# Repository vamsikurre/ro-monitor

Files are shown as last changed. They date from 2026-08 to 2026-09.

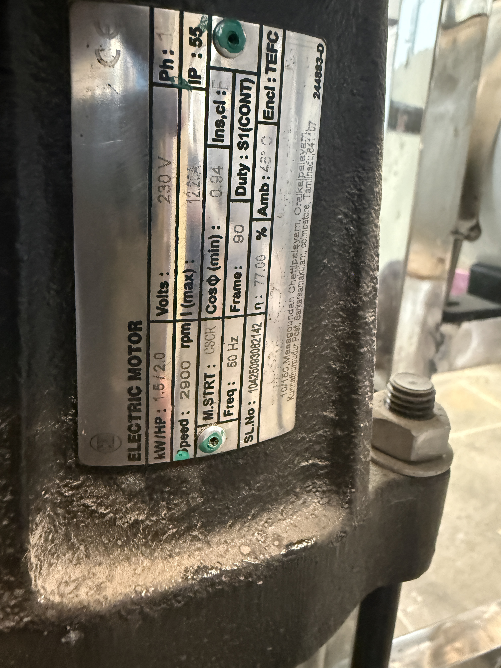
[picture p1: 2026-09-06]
images/hardware/nameplate_hpp_motor_2hp.jpg

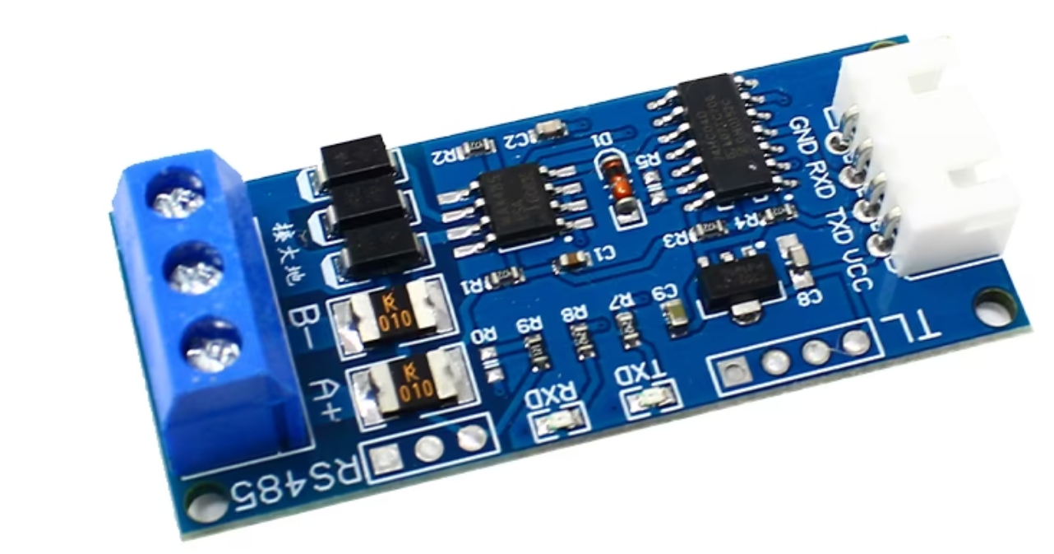
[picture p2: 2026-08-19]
images/hardware/RS485-transcever-board-f.png

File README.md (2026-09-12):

# RO-Monitor: Industrial RO Plant Remote Telemetry & Monitoring System

A non-invasive, galvanically isolated telemetry, environmental, and multi-zone liquid level monitoring system for commercial/industrial Reverse Osmosis (RO) plants.

The system interfaces with an existing **Aster NXT 11** RO controller, distributed rooftop/battery-room storage and environmental nodes using an **ESP32-S Master Hub** over an **RS485 Daisy-Chain Bus**, and connects to **Ground Floor Sump and Motor Starter Nodes** over **Local Wi-Fi (LAN)**. It features a responsive **Local Web Dashboard** and native **ESP RainMaker Cloud** integration for iOS & Android mobile telemetry and push notifications.

---

## 1. System Architecture Overview

```
                                      +------------------------------------------+
                                      |              230V AC Mains               |
                                      +--------------------+---------------------+
                                                           |
                                                           v
                                               +-----------------------+
                                               |  Hi-Link HLK-20M12    |
                                               |  (12V DC / 20W Power) |
                                               +-----------+-----------+
                                                           |
                                                           | 12V DC Distributed Bus
                                                           v
 [NO TERMINATOR - see docs/WIRING.md 12.3]
+----------------------------------------------------------------------------------------------------+
|                                    ESP32-S CENTRAL HUB (RO ROOM)                                   |
|  - Microcontroller: ESP32-S (38-Pin)                                                               |
|  - RS485 Interface: XY-485 Hardware Auto-Flow Control Transceiver (UART2: GPIO16 RX / GPIO17 TX)   |
|  - High Voltage Isolation: 2x 220V AC Optocouplers (HPP Contactor & RWP Relay Active Monitoring)   |
|  - Low Voltage Isolation: 4-Channel PC817 Optocoupler Board (Aster Float, Relay & Alarm Contacts) |
|  - Dosing Tank Level: AJ-SR04M wired DIRECT to hub (GPIO 5 / GPIO 4 + divider) - no RS485 node    |
|  - Local Environmental: GY-SHT30-D Digital Temperature & Humidity Sensor (I2C: GPIO21 / GPIO22)    |
|  - 4-Channel Relay Board: TWT Float, RWT Float, Dosing Level Emulation                             |
|  - Connectivity: Local Web Dashboard Server & ESP RainMaker AWS IoT Agent                          |
+--------------------------------------------------+-------------------------------------------------+
                                                   |
                                                   | Cat5e 1 (Battery Room Outbound Blue Pair)
                                                   v
+--------------------------------------------------+-------------------------------------------------+
|                                  NODE 0x04: BATTERY ROOM CLIMATE & FAN                             |
|  - Microcontroller: Arduino Pro Mini (ATmega328P-AU, 5V / 16MHz) | Location: Battery Room         |
|  - Sensor: GY-SHT30-D Digital Temperature & Humidity Sensor                                        |
|  - Output: 1-Channel Relay Module (Exhaust Fan Control)                                            |
|  - Bus Position: MID-CHAIN - no termination resistor                                               |
+--------------------------------------------------+-------------------------------------------------+
                                                   |
                                                   | Cat5e 2 (Roof Top Outbound Blue Pair)
                                                   v
+--------------------------------------------------+-------------------------------------------------+
|                                  NODE 0x03: TREATED WATER TANK (TWT)                               |
|  - Microcontroller: Arduino Nano (ATmega328P) | Location: Roof Top                                 |
|  - Sensor: AJ-SR04M Waterproof Ultrasonic Sensor                                       |
+--------------------------------------------------+-------------------------------------------------+
                                                   |
                                                   | Cat5e 3 (Roof-to-roof Outbound Blue Pair)
                                                   v
+--------------------------------------------------+-------------------------------------------------+
|                                    NODE 0x02: RAW WATER TANK (RWT)                                 |
|  - Microcontroller: Arduino Nano (ATmega328P) | Location: Roof Top                                 |
|  - Sensor: AJ-SR04M Waterproof Ultrasonic Sensor                                       |
|  - Bus Termination: NONE - no bias network, see docs/WIRING.md 12.3                                |
+----------------------------------------------------------------------------------------------------+

                                                   ▲
                                                   │ (Wi-Fi 2.4GHz LAN)
                                                   ▼
======================================================================================================
                                    GROUND FLOOR PARKING ECOSYSTEM
======================================================================================================
+--------------------------------------------------+-------------------------------------------------+
|                         ESP32 NODE 1: GROUND SUMP TELEMETRY (0x05)                                 |
|  - Microcontroller: ESP32-WROOM-32 / ESP32-C3                                                      |
|  - Sensor: AJ-SR04M Ultrasonic Sensor (3.5m Deep Sump Pit)                                        |
|  - Power: Hi-Link HLK-20M5 (240V AC -> 5V DC 4A)                                                   |
+--------------------------------------------------+-------------------------------------------------+
                                                   | (Wi-Fi 2.4GHz LAN)
                                                   v
+--------------------------------------------------+-------------------------------------------------+
|                   ESP32 NODE 2: MOTOR MONITORING & STARTER CONTROL (0x06)                          |
|  - Microcontroller: ESP32-WROOM-32 / ESP32-C3                                                      |
|  - Power: Hi-Link HLK-20M5 (240V AC -> 5V DC 4A)                                                   |
|  - Inputs: 2x 220V AC Optocouplers (Sump Motor Active & Borewell Motor Active)                     |
|  - Outputs: 4-Channel Relay Board (Sump Float & Borewell Float Starter Cutoff / Interlock)        |
+----------------------------------------------------------------------------------------------------+
```

---

## 2. Process Flow & Dashboard Architecture

The system telemetry directly visualizes the plant's water balance and environmental status:

```
[Borewell Pump] ──> [Ground Sump (3.5m)] ──(Sump Motor)──> [RWT (Roof)] ──> [RO Plant: RWP + Dosing + HPP] ──> [TWT (Roof)]
                                                                               │
                                                                               └── [Battery Room: SHT30 + Exhaust Fan]
```

### Local Web Dashboard Features:
- **Zero-Cloud LAN Access:** Hosted directly on the local network (accessible at `http://ro-hub.local` or Hub IP).
- **Animated Liquid Graphic:** Live animated fluid levels for Sump, RWT, Dosing, and TWT tanks.
- **Dynamic Motor Indicators:** Real-time running/idle status for Borewell Pump, Sump Motor, Raw Water Pump (RWP), and High Pressure Pump (HPP).
- **Climate & Ventilation Cards:** RO Room & Battery Room Temperature/Humidity gauges with Exhaust Fan auto/manual controls.

### ESP RainMaker Mobile Cloud Integration:
- **Native iOS & Android App:** Remote monitoring from anywhere in the world.
- **Push Notification Alerts:**
  - `CRITICAL:` Ground Sump Low (< 15%) / Dry Run Risk.
  - `WARNING:` Tank Overflow Risk (Sump/RWT/TWT > 95%).
  - `ALERT:` High Battery Room Temperature (> 38°C) $\to$ Automated Exhaust Fan Trigger.
  - `FAULT:` RO Controller Alarm Relay Activated.

---

## 3. Node Addressing & Telemetry Matrix

| Node ID | Subsystem | Transport | Hardware Platform | Primary Sensors & Actuators |
| :---: | :--- | :--- | :--- | :--- |
| `0x00` | **RO Room (Central Hub)** | Core Master | ESP32-S (38-Pin) | SHT30 (RO Room), AJ-SR04M (Dosing, direct), 2x AC Optos, 4x DC Optos, 4-Ch Relay Board |
| — | **RO Room (Dosing)** | *Direct to hub* | — | AJ-SR04M on hub GPIO 5 / GPIO 4 (address `0x01` retired) |
| `0x02` | **Roof Top (RWT)** | RS485 Bus | Arduino Nano | AJ-SR04M (Raw Water Tank Level). No bus termination — `docs/WIRING.md` §12.3 |
| `0x03` | **Roof Top (TWT)** | RS485 Bus | Arduino Nano | AJ-SR04M (Treated Water Tank Level) |
| `0x04` | **Battery Room** | RS485 Bus | Arduino Pro Mini | GY-SHT30-D (Battery Room Temp/RH) + 1-Ch Exhaust Fan Relay (mid-chain, no term) |
| `0x05` | **Ground Floor (Sump)** | Wi-Fi LAN | ESP32 | AJ-SR04M (3.5m Sump Level Sensor) |
| `0x06` | **Ground Floor (Motors)**| Wi-Fi LAN | ESP32 | 2x AC Optos (Sump/Borewell Motors), 4-Ch Relay Board |

---

## 4. Build Phases

The project is built **by site**, terrace first, then ground floor. Each phase is a system that works on its own.

| | Phase 1 — Terrace | Phase 2 — Ground floor |
| :--- | :--- | :--- |
| **Scope** | RO room, battery room, roof tanks | Sump, borewell, starter panel |
| **Nodes** | Hub `0x00`, RWT `0x02`, TWT `0x03`, Battery Room `0x04` | Sump `0x05`, Starter panel `0x06` |
| **Sensing** | 3 tank levels, 2 room climates, Aster contacts, HPP + RWP current | Sump level, sump + borewell current, borewell dry-run |
| **Status** | Node firmware done and bench-tested; hub bring-up in progress | Not started; clamps in hand |

**One exception crosses the line.** The sump **dry-run float** (`superpowers/specs/…-phase-b-design.md` §1.1) is ground-floor work that should be fitted during Phase 1. It needs no firmware and no node — a float, some cable, an afternoon — and until it exists the sump motor can still run dry, which is the failure this project was started to prevent. Terrace-first would otherwise leave that pump unprotected for the whole of Phase 1.

---

## 5. Firmware

| Firmware | Board | Toolchain | Notes |
| :--- | :--- | :--- | :--- |
| `firmware/ro_node/` | Nano ×2, Pro Mini ×1 | Arduino | **One binary for all three RS485 nodes.** The `A0`/`A1` jumpers pick the address *and* the personality: `0x02`/`0x03` ultrasonic, `0x04` climate + fan. Nothing to edit per board. |
| `firmware/hub_prod/` | ESP32-S hub | **ESP-IDF** | **Production hub.** RS485 master, local dashboard, password-protected calibration page, ESP RainMaker cloud with push alerts, and OTA updates from the RainMaker dashboard. Built the same way as `gate-controller`, so one update workflow covers both. See `firmware/hub_prod/README.md`. |
| `firmware/esp32_hub_test/` | ESP32-S hub | Arduino | **Bench self-test.** Cycles all five relays, injects nothing, prints raw millivolts per channel per cycle over USB at 115200. Kept deliberately: commissioning a board and running a plant are different jobs. |

**Flashing the nodes:** jumper first, flash second, then confirm the boot print
(`Node ID: 0x02 … role: RWT ultrasonic`) before putting the board on the bus. Both
jumpers grounded is the deliberate "unassigned" code — the node blinks and stays off the
bus rather than guessing an address. Pro Mini: `Arduino Pro or Pro Mini` / *ATmega328P
(5V, 16 MHz)*, `DTR` wired, and pull the buck's 5 V while the FTDI adapter is connected.

**Production hub, in one block:**

```
cd firmware/hub_prod
idf.py set-target esp32 && idf.py build && idf.py -p COM5 flash monitor
```

Pair from the ESP RainMaker app with proof-of-possession `rohub1234`, over BLE.
After that the dashboard is at `http://ro-hub.local/`, calibration at `/cal`
(user `admin`), and firmware updates are pushed from the RainMaker dashboard —
no cable, exactly like the gate controllers. The hub keeps its own AP up at the
same time, so calibration still works on a roof with no router.

**Calibration is hub-side and needs no cable.** Nodes report millimetres; the hub turns
them into percentages. On the bench sketch, join the hub's Wi-Fi AP (`RO-HUB`) and open `http://192.168.4.1/`
— every tank has a full and an empty distance, and a **Set full = now** button that
captures whatever the sensor reads at that moment. Fill the tank, tap it; drain it, tap
**Set empty = now**. Values persist in NVS across reboots and reflashes of the nodes.
`GET /api/cal` returns the same thing as JSON. Until a tank is calibrated its level
reads `--`, never a plausible wrong number.

**The battery room fan thresholds live on the same page.** The hub reads the room
temperature from node `0x04`, applies its own hysteresis and commands the relay, so
changing the setpoint is a phone, not a programmer on a ladder. Accepted range is
25.0–55.0 °C with ON at least 1.0 °C above OFF. If the hub goes quiet for five
minutes the node falls back to its own hotter backstop (40.0 / 37.0 °C) and keeps
ventilating regardless.

**Checks** (plain Python, run from the repo root — no framework, no CI):

```
python docs/check_addrmap.py   # jumper table agrees across docs and firmware
python docs/check_pinmap.py    # GPIO allocation agrees across 3 docs AND app_priv.h
python docs/check_frame.py     # node, bench hub and production hub agree on
                               # CRC-16, framing and level maths
python docs/check_telemetry.py # /api/telemetry is valid JSON and carries every
                               # key the dashboard reads - it falls back to its
                               # demo simulator on any error, so a broken
                               # contract looks like a working page
```

**Compile both before flashing** — `arduino-cli` ships inside the Arduino IDE install
(`.../Arduino IDE/resources/app/lib/backend/resources/arduino-cli.exe`):

```
arduino-cli compile -b arduino:avr:nano  firmware/ro_node
arduino-cli compile -b esp32:esp32:esp32 firmware/esp32_hub_test
cd firmware/hub_prod && idf.py build          # the production hub
```

Each sketch also carries a `#error` guard for the wrong target, so selecting the ESP32
for `ro_node` tells you that in one line instead of failing inside `SoftwareSerial.h`.

---

## 6. Detailed Documentation Index

For in-depth technical documentation, refer to the guides in the `docs/` folder:

* **`PCB_HUB_MOTHERBOARD.md`** — net-level schematic specification for a fabricated
  hub board. Specification only; nothing designed or ordered. Also serves as the
  first complete net-level record of the hub as wired.
- **[Hardware Specifications & Pin Allocations](docs/HARDWARE.md)**
- **[Terminal-by-Terminal Wiring Guide](docs/WIRING.md)**
- **[RS485 & Wi-Fi Master-Slave Protocol Specification](docs/RS485_PROTOCOL.md)**
- **[Power Budget & Voltage Drop Calculations](docs/POWER_BUDGET.md)**
- **[Local Web Dashboard & ESP RainMaker Integration Guide](docs/DASHBOARD_AND_RAINMAKER.md)**
- **[Skid Hardware Reverse Engineering Analysis](docs/RO_HARDWARE_ANALYSIS.md)**
- **[Credentials: every hardcoded password and default](docs/CREDENTIALS.md)**

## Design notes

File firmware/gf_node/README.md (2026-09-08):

# gf_node — ground-floor Wi-Fi nodes

One ESP-IDF project, two roles. Polled by the terrace hub over the LAN
(`docs/superpowers/specs/2026-09-07-ground-floor-wifi-nodes-design.md`).

| Role | Node | Reads |
| :--- | :--- | :--- |
| Sump | `0x05` | AJ-SR04M ultrasonic, or a 4-20 mA transducer when `J-PRESS` is shunted |
| Utility | `0x06` | 3 borewell CTs, 3 sump-motor CT channels, Astero `PUMP ON`, RWT floaty, SHT30 |

## Build

ESP-IDF 5.4.4 shell:

```powershell
. C:\Espressif\tools\Microsoft.v5.4.4.PowerShell_profile.ps1
cd C:\orbit\git_repos\ro-monitor\firmware\gf_node
```

One tree, two roles, and **one thing you must not skip**: ESP-IDF keeps a
single `sdkconfig` at the project root no matter which `-B <dir>` you build
into. `-B` only chooses where the compiled *output* goes — the config file
that decides which role gets compiled still resolves to the same shared path
unless you also pin it with `-D SDKCONFIG=<dir>/sdkconfig`. Build both roles
with `-B build_sump` / `-B build_util` alone and the second `idf.py`
invocation you run — on *either* directory, even a routine rebuild — silently
reconfigures whichever directory it touches to match whatever role was
configured last. Both `.bin` files come out looking fine and are the same
firmware.

That is not hypothetical: it happened while this project was first built,
and it does not show up as a build error. It shows up on the hub, later, as
a node that reports the wrong `id` in `/api/telemetry`, gets rejected
wholesale by the hub's parser, and shows as offline with nothing but
`unparseable reply` in the log — because a sump-role hub config was received
from a utility-labelled binary, or vice versa.

The fix is to pass `-D SDKCONFIG=<build dir>/sdkconfig` on **every**
invocation for both roles, not only on `set-target`:

```powershell
# Sump role (the default Kconfig choice)
idf.py -B build_sump -D SDKCONFIG=build_sump/sdkconfig set-target esp32
idf.py -B build_sump -D SDKCONFIG=build_sump/sdkconfig menuconfig   # SSID, password, static IP
idf.py -B build_sump -D SDKCONFIG=build_sump/sdkconfig build
idf.py -B build_sump -D SDKCONFIG=build_sump/sdkconfig -p COMx flash monitor

# Utility role
idf.py -B build_util -D SDKCONFIG=build_util/sdkconfig -D SDKCONFIG_DEFAULTS="sdkconfig.defaults;sdkconfig.util" set-target esp32
idf.py -B build_util -D SDKCONFIG=build_util/sdkconfig menuconfig   # SSID, password, static IP
idf.py -B build_util -D SDKCONFIG=build_util/sdkconfig build
idf.py -B build_util -D SDKCONFIG=build_util/sdkconfig -p COMx flash monitor
```

`-D SDKCONFIG_DEFAULTS` only matters on `set-target`, since that is the step
that seeds a *new* config file from `sdkconfig.defaults` plus
`sdkconfig.util`. `-D SDKCONFIG=<dir>/sdkconfig` matters on every command,
forever — drop it once and the next invocation falls back to the shared root
file again.

`sdkconfig.util` is **hand-authored and committed**, not generated — it is
the utility role's two-line overlay (`CONFIG_GF_ROLE_UTILITY`,
`CONFIG_GF_STATIC_IP`) layered onto `sdkconfig.defaults` via
`SDKCONFIG_DEFAULTS` above. It is not disposable the way `sdkconfig` or
`sdkconfig.old` are (both gitignored, both regenerated by `set-target`) —
deleting it means nobody can reproduce the utility build from a clean
checkout.

The static IP you set in `menuconfig` is what you type on the hub's `/cal`
page. Give it a reservation on the router too, or pick one outside the DHCP
pool.

## Flash (first time, over USB)

Already shown above per role: `idf.py ... -p COMx flash monitor`. Watch the
monitor for `up at <the static IP>`, then confirm from another machine on
the LAN:

```
curl http://192.168.1.51/api/telemetry
```

## OTA (every time after that)

Two app slots (`partitions.csv`), rollback on
(`CONFIG_BOOTLOADER_APP_ROLLBACK_ENABLE`). From any PC on the LAN, no USB
needed:

```
curl --data-binary @build_sump/gf_node.bin http://192.168.1.51/ota
```

The node streams the image into whichever slot is not currently running,
validates it (`esp_ota_end` checks the image header and checksum — a text
file or a truncated upload is refused with `400` before it is ever booted),
and reboots into it. `POST /ota` replies before the reboot:

**Nothing here catches the wrong role's `.bin`.** It is a perfectly valid
ESP32 app image: it passes the checksum, flashes, boots, answers
`/api/telemetry` and therefore confirms itself and cancels its own rollback.
What you get is the failure described at the top of this file — a node that
reports the wrong `id` forever while the hub logs only `unparseable reply`.
So after every push, fetch the node's root page and read the role and id back:

```
curl http://192.168.1.51/
gf_node sump id 5 fw v1.4.2-3-gab12cd4
```

| Response | Meaning |
| :--- | :--- |
| `200 OK N bytes, rebooting into ota_N` | written, validated, rebooting |
| `400` | body too small, or not a valid ESP32 app image |
| `408` | transfer stalled for 60 s (a dropped-association Wi-Fi failure looks like this, not like a clean disconnect) |
| `413` | image larger than the OTA slot |
| `500` | no free partition, the OTA write could not be started, connection dropped, flash write failed, or the image is valid but the boot pointer could not be set — each with its own reason string in the body |

None of the failure responses reboot the node or leave the target slot in a
state that blocks a second attempt — a bad push just means try again. That
includes a stall: without the 60 s deadline, a silently-dropped Wi-Fi
association mid-transfer would leave the handler blocked forever, taking
telemetry and every future OTA attempt down with it until someone power-cycled
the node — the deadline exists specifically so that failure mode ends in a
`408` and a free node, not a trip to a manhole.

The new image boots **pending-verify**. `main.c`'s watch marks it good only
once the node has Wi-Fi **and** has answered one `/api/telemetry` request;
if that has not happened within 120 s (`OTA_CONFIRM_MS`, `gf.h`) it reboots
into the previous image by itself. So a build with the wrong SSID or
password costs two minutes of monitor log, not a trip to a manhole or a
motor starter panel.

The hub shows each node's `fw` (the git description) in its node list, which
is how you know a push actually landed. It does not show the role, which is
why the `curl http://<node>/` above is the check that matters.

A push during the 120 s confirmation window is refused: `esp_ota_begin()`
returns `ESP_ERR_OTA_ROLLBACK_INVALID_STATE` while the running image is still
on trial, and the `500` says so. Wait it out, or let it roll back, then push
again.

### Built size per role

Both roles are the same tree; the difference is which `sensors_*.c` and which
role constants compile in. Against the 0x1E0000 (1920 KB) OTA slots in
`partitions.csv`, measured 2026-09-08 on ESP-IDF 5.4.4:

| Role | `gf_node.bin` | Free in the slot |
| :--- | ---: | ---: |
| Sump `0x05` | 743,744 bytes (0xB5940) | 62 % |
| Utility `0x06` | 759,104 bytes (0xB9540) | 61 % |

**The two sizes differing is itself the check that you built two roles** — the
`-D SDKCONFIG=` trap at the top of this file produces two identical `.bin`
files, and identical byte counts are the first thing that shows it. Confirm
properly with `strings gf_node.bin | findstr /x sump utility`, or from
`build_<role>/config/sdkconfig.h`, which must carry `CONFIG_GF_ROLE_SUMP` or
`CONFIG_GF_ROLE_UTILITY` and never both.

The tail of each build prints its own `gf_node.bin binary size` line.

## What it answers

`GET /` — one line of identity. `GET /api/telemetry` — the JSON in the spec
§4, raw readings only; every calibration number lives on the hub.
`POST /ota` — above.

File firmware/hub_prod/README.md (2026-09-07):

# RO Monitor — Central Hub, production firmware

ESP-IDF firmware for the ESP32-S central hub. Built the same way as
`gate-controller` in this workspace, deliberately: same framework, same RainMaker
component, same two-slot OTA layout, same BLE pairing flow. If you can update the
gates over the air, you can update this the same way, from the same dashboard.

The bench sketch at `../esp32_hub_test/` stays where it is. It is a self-test
harness — it cycles relays and prints raw millivolts — and that is a different
job from running the plant. Keep it for commissioning a new board.

---

## What it does

| | |
| :--- | :--- |
| **RS485 master** | Polls node `0x02` (RWT), `0x03` (TWT), `0x04` (battery room climate + fan) every 2 s |
| **Local sensing** | RO-room SHT30, dosing-tank ultrasonic, 4 PC817 dry contacts, 2× 240 V opto, 2× SCT-013 clamp |
| **Fan policy** | Owns the battery-room thresholds and commands the relay over RS485; the node keeps a hotter backstop |
| **Local dashboard** | `http://ro-hub.local/` — the existing 1400-line page, embedded in flash |
| **Calibration** | `http://ro-hub.local/cal` — password protected; tanks, clamps, fan thresholds |
| **Cloud** | ESP RainMaker: five devices, live telemetry, push alerts |
| **OTA** | `esp_rmaker_ota_enable_default()` — push from the RainMaker dashboard |

**Nothing in this firmware moves water.** The only actuator it commands is the
battery-room exhaust fan. The four float-emulation relays on the board are driven
to de-energised at boot and then left alone — that is Phase C, and it stays that
way until the staged-adoption criteria in phase-B spec §7.2 are met.

---

## Build and flash

ESP-IDF **v5.2 or newer** (developed and verified against v5.4.4).

```bash
# once per shell
. $IDF_PATH/export.sh                 # Windows: the Espressif PowerShell profile

cd firmware/hub_prod
idf.py set-target esp32               # pulls esp_rainmaker, mdns, rmaker_app_network
idf.py build
idf.py -p COM5 flash monitor
```

`sdkconfig` is generated and **not** tracked — `sdkconfig.defaults` is the source
of truth. Delete `sdkconfig` and rebuild if the config ever looks wrong.

---

## Looking at the running dashboard

`.mcp.json` at the repo root registers the Playwright MCP server, so the live
page can be opened in a real browser rather than guessed at from source. It is
headless and isolated (no profile written to disk), and its origin allowlist is
the hub only.

This is worth doing before calling a dashboard change done. Fetching
`/api/telemetry` with curl proves the JSON; it cannot show a console error, a
failed request, or where an element actually landed on the page. Both of these
were found that way and neither could have been caught by a checker:

- `/favicon.ico` 404ing twice per page load, in a log whose value depends on a
  warning meaning something
- the sump sitting 44 px below the ground line it was supposed to meet - verified
  fixed by measuring `sump.top === earth.top` in the rendered DOM, not by eye

**Fetching the page with plain `curl` returns 406.** It is stored gzipped and the
body says so; use `curl --compressed`, or a browser, which always sends
`Accept-Encoding: gzip`.

---

## OTA from the RainMaker dashboard

Wired and enabled: `esp_rmaker_ota_enable_default()` in `app_main.c`, two 1.84 MB
app slots in `partitions.csv`, HTTPS transport, 3 retries 5 minutes apart. Push a
job from the dashboard and the node acts on it over its OTA topic. The current
image is 1.5 MB, so a new one has room in the other slot.

Three things were fixed on 2026-09-01 before this could be relied on:

| | Was | Now |
| :--- | :--- | :--- |
| **Automatic rollback** | off — `CONFIG_BOOTLOADER_APP_ROLLBACK_ENABLE` unset, so `ROLLBACK_WAIT_PERIOD=90` was inert | **on.** A new image boots as *pending verify* and is only marked good once it reaches the cloud. If it cannot within 90 s, the ESP reboots into the previous slot on its own |
| **Autofetch period** | `3600` in `sdkconfig.defaults` — the unit is **hours**, range 0-168, so it was out of range, ignored, and the build ran with `0` (ask once per boot) | **24** — a daily catch-up for jobs missed while offline |
| **Reported version** | `PROJECT_VER` unset and a hand-maintained `FW_VERSION "1.0.0"` in `app_priv.h` that never left the header | **The version is the git description.** `CMakeLists.txt` runs `git describe --always --tags --dirty` into `PROJECT_VER`, and the banner, the RainMaker `Firmware` attribute and the dashboard footer all read it back from the app descriptor |

Rollback matters more on this build than on most. The onboard USB-serial is
destroyed (`WIRING.md` §0.3.1) and the local AP is now off, so an OTA image that
boots but cannot connect would leave **no way in at all** short of an FTDI and the
BOOT/EN dance in the plant room. With rollback on, that image reverts itself.

### The version is the commit

`1.0.0` was a number somebody had to remember to bump, and RainMaker refuses an
update whose version equals the running one — so a forgotten bump shows up as an
OTA that silently declines with *"Current running version is same as the new"*,
blaming the version rather than the habit. The version is now whatever
`git describe --always --tags --dirty` says:

| On the device | Means |
| :--- | :--- |
| `a3cb57d` | exactly that commit |
| `a3cb57d-dirty` | that commit **plus uncommitted changes** — you flashed a tree that is not in git |
| `v1.2-4-ga3cb57d` | 4 commits past tag `v1.2`, if anything is ever tagged |

Ordering is not required: RainMaker only checks that the two version strings
*differ*, never that the new one is greater, so a hash is a complete answer.

Commit before you build if you want the hash to mean anything — `-dirty` is the
build telling you it cannot identify what is on the box. Configure re-runs when
`.git/HEAD` or `.git/index` changes, so a fresh commit updates the version
without a manual `idf.py reconfigure`; if a version ever looks stale, that is the
command.

---

## First-boot pairing

Provisioning is over **BLE**, not SoftAP. That used to be what kept the hub's own
access point free to serve `/cal` at the same time; the AP is off as of
2026-09-01 and BLE remains the transport because it does not contend with the
station link.

1. ESP RainMaker app → **Add Device**
2. Scan the QR code printed on the serial console
3. Proof of possession: **`rohub1234`** (static, so pairing never needs the console)
4. Choose the site Wi-Fi

Boot button: hold **3 s** to clear Wi-Fi credentials and re-provision, **10 s**
for a full factory reset.

---

## Reaching it afterwards

Both interfaces stay up, always. Calibration happens standing next to a tank on a
roof, which is where the house Wi-Fi is least reliable — and it is also what you
need when the *router* is the thing that has failed.

| Path | Address |
| :--- | :--- |
| Over the LAN | `http://ro-hub.local/` or the DHCP address |
| Hub's own AP | **Disabled** as of 2026-09-01 (`AP_MODE_ENABLED 0`, `app_priv.h`). Dashboard and `/cal` are LAN-only. Set to `1` and reflash to restore `RO-HUB` / `ro-monitor` → `http://192.168.4.1/` |
| Calibration | `/cal` — user `admin`, password `ro-calibrate` (change it on that page) |

Change the calibration password on first commissioning. It is stored in NVS, so
it survives a reflash but not a factory reset.

The two ground-floor Wi-Fi nodes have their own build, flash and OTA
instructions — `firmware/gf_node/README.md`. This hub only needs their IPs,
typed on `/cal` below.

---

## Ground-floor nodes on the bench

No node hardware needed to prove the hub side:

```
python docs/fake_gf_node.py --role sump --port 8085
python docs/fake_gf_node.py --role util --port 8086
```

On `/cal` → Ground floor nodes, enter `<PC IP>:8085` and `<PC IP>:8086`. Within
5 s the dashboard's sump, borewell and sump-motor cards un-hatch and the node
list shows both as Online with `fw fake`.

Then: `curl "http://<PC>:8085/silent?on=1"` — after ~15 s the sump card hatches,
the event log shows `Node offline 0x05 Sump`, the console says it is probing
every 30 s. `curl "http://<PC>:8085/silent?on=0"` — within 30 s it is back.

Clear the IP field and save: the node goes to "not fitted", cards hatch, no
alert. The IPs are the only thing this stores; nothing else on the node side
survives a node reflash because nothing else lives there.

---

## Calibration page

Everything on this page is range-checked before it is stored — a typo must
not be able to produce a reading that looks plausible and is wrong.

**Tanks.** Full and empty distances in millimetres, transducer face to liquid
surface. Empty must be the longer distance, and full must clear the 200 mm blind
zone. The live reading is shown next to each field. The **sump** row also takes
a transducer range in mm (0 when the ultrasonic is fitted) and shows which
source node `0x05` actually reported, so a wrong `J-PRESS` shunt is visible
from the roof, not the manhole.

**Current clamps.** Amps per volt, turns, run threshold and the over-current
trip — now four rows, not two: HPP, RWP, **Borewell**, and **Sump motor**.
- An SCT-013-030 is nominally **30 A/V**, but two-point calibrate against a clamp
  meter. This is a trend instrument; consistency beats absolute accuracy.
- **Turns** is how many times the conductor passes through the jaws. A ~5 A pump
  gives only ~170 mV from a 30 A clamp, so 2–3 turns is usually worth it. The
  reading divides by this, and nothing else records it — write it on the
  enclosure too (`WIRING.md` §14.3).
- HPP and RWP show each channel's **pedestal** in millivolts. ~1650 mV means the
  bias breakout is correct. Anything else means no current will be reported at
  all, deliberately: a floating input produces a large and entirely fictional
  RMS figure, which is the worst possible failure for a dry-run detector.
- **Borewell and sump motor show live per-phase amps** instead — one clamp
  calibration applies to all three channels of each motor. The borewell's
  **run threshold** is what turns a phase current into `RUNNING`, since that
  motor has no contact of its own; the sump motor's running state is the
  Astero `PUMP ON` contact regardless of what the clamps read.

**Ground floor nodes.** Sump and Utility node IPs (`gf_sump_ip`, `gf_util_ip`),
polled every 5 s. Empty = not fitted: nothing is polled, nothing alerts, and
the dashboard hatches that node's cards. See "Ground-floor nodes on the
bench" above for testing this with no node hardware.

**Fan.** On/off thresholds, clamped to 25.0–55.0 °C with at least 1.0 °C of
hysteresis enforced.

---

## RainMaker devices

Follows `docs/DASHBOARD_AND_RAINMAKER.md` §3.1.

```
RO Plant Monitor - XXXX
├── Water Tanks      Raw Water Level, Treated Water Level, Dosing Level, Sump Level, RWT Float Full
├── Pumps & Motors   HPP/RWP Running, HPP/RWP Current, Over Current
├── Environment      RO Room + Battery Room temperature and humidity
├── Ventilation      Exhaust Fan (read-only), Fan On Above (slider, writable)
├── Ground Floor     Borewell/Sump Motor Running, Borewell/Sump Motor Current, Utility Room temperature and humidity
└── RO Plant         Status (text), Controller Fault
```

Everything is read-only except the fan threshold. This hub publishes
measurements, and a measurement is not a control. Calibration deliberately lives
on `/cal` rather than in the app: it needs a live distance reading while you
stand next to the tank, which a phone notification cannot give you.

Values are reported **on change past a deadband**, not every cycle — fourteen
parameters at a 2 s cadence is a lot of MQTT for readings that mostly do not move.
Tank levels use 3 %: ultrasonic jitter straddling a 1 % boundary published every
cycle and exhausted the RainMaker MQTT budget (refilled at one message per 5 s) —
`Out of MQTT Budget. Dropping publish message.`, seen 2026-09-07.

## Alerts

Push notifications per `DASHBOARD_AND_RAINMAKER.md` §4, plus over-current, which
post-dates that table.

Each alert latches, needs the value to return past a margin before it can fire
again, and has a five-minute floor between repeats. An alert that cries wolf
teaches somebody to mute the app, and a muted app protects nothing. Over-current
additionally has to persist three cycles: one bad RMS read — a contactor closing
mid-window, a loose 3.5 mm plug — is not a fault.

The controller-fault alert says that something tripped but never *which*. The
Aster multiplexes every condition onto the one `AUX OP` contact (`WIRING.md`
§6.3), so text naming a cause would be a guess.

---

## Verification

The ported logic is checked against the field-verified bench sketch, not just
eyeballed:

```bash
python docs/check_frame.py     # CRC-16 and level maths, all three copies
python docs/check_pinmap.py    # 20 GPIOs across 3 documents + app_priv.h
python docs/check_addrmap.py   # node address jumper table
```

`check_frame.py` compiles `crc16()` and `levelPercent()` out of this firmware
alongside the sketch's copies and sweeps them against each other — a divergence
in the middle of the range, not just at the boundaries, fails the build.

`check_pinmap.py` now treats `app_priv.h` as a fourth source. It used to compare
documents to documents only, and that gap cost a day: `IN_ALARM` on GPIO 33 sat
in all three tables, passed the check, and was read by no firmware at all.

---

## Known limits

- **Ground floor nodes are polled, not RS485.** Sump level, borewell and
  sump-motor state come from nodes `0x05`/`0x06` over the house LAN
  (`RS485_PROTOCOL.md` §5), not the RS485 bus — the addresses are kept for
  consistency with the rest of the node table, nothing more. An unconfigured
  or unreachable node is reported as `OFFLINE` rather than as zeros, so the
  dashboard hatches its cards instead of drawing an empty tank that looks
  measured.
- **Calibration auth is HTTP Basic over plain HTTP** on the local network. The
  thing protected is a calibration constant; the alternative is provisioning and
  renewing a TLS certificate on an embedded box. Revisit if this ever gains a
  control that moves water.
- **CT channels are sampled one per cycle**, so each refreshes every ~4 s. Motor
  start and stop come from the contactor optos, which are instant, so nothing is
  lost — but the current figure is a trend, not an interlock input.

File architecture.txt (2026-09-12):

===============================================================================
               RO-MONITOR: COMPLETE MULTI-ZONE SYSTEM ARCHITECTURE
===============================================================================

-------------------------------------------------------------------------------
1. TERRACE & ROOF TOP SUBSYSTEM (RS485 DAISY-CHAIN BUS + 12V DC DISTRIBUTION)
-------------------------------------------------------------------------------

Physical Layout:
- Central Skid & Dosing Tank in RO Room (dosing sensor lands straight on the hub, ~1 m).
- Raw Water Tank (RWT) and Treated Water Tank (TWT) on Roof Top in opposite directions.
- Battery Room with Exhaust Fan & Climate monitoring, spliced mid-chain between the RO Room and the Roof.

Electrical Topology: 100% Strictly Linear Daisy-Chain, single outbound walk
Chain order: 0x00 HUB -> 0x04 BATTERY ROOM -> 0x03 TWT -> 0x02 RWT
Terminators: NONE - this bus has no bias network and fails with one fitted.
             See docs/WIRING.md 12.3. No loopback, no junction box.
Dosing tank (~1 m from hub): AJ-SR04M wired DIRECT to the ESP32, not an RS485 node.
  Address 0x01 is retired. See docs/WIRING.md section 13.

 [NO TERMINATOR - docs/WIRING.md 12.3]
┌─────────────────────────────────────────────────────────┐
│                      ESP32-S HUB                        │  (Bus Master, 0x00 - RO Room)
│  - XY-485 Auto-Flow Control Transceiver                 │
│  - Astero NXT 11 AC Isolators (HPP & RWP AC Monitoring) │
│  - Astero NXT 11 DC Isolators (TWT, RL1, RL2, ALARM)    │
│  - AJ-SR04M DIRECT: dosing tank level (GPIO 5 / GPIO 4)│
│  - 4-Channel Relay Board (TWT Floty, RWT Floty, DOS LVL)│
│  - Local Enclosure Climate: GY-SHT30-D (I2C)            │
│  - Local Web Dashboard Server & ESP RainMaker Cloud     │
└────────────────────────────┬────────────────────────────┘
                             │
                             │ Cat5e 1 (length TBM): Outbound Pair (Blue / White-Blue)
                             ▼
┌─────────────────────────────────────────────────────────┐
│             NODE 0x04: BATTERY ROOM NODE                │  (Slave Node 0x04 - Battery Room)
│  - Arduino Pro Mini (5V/16MHz) + XY-485 Module           │
│  - 5V fed to VCC pin; RAW pin left unconnected           │
│  - GY-SHT30-D Digital Temp & Humidity Sensor (I2C)      │
│  - 1-Channel Relay Module (Exhaust Fan Control)         │
│  - MID-CHAIN: no termination resistor                   │
└────────────────────────────┬────────────────────────────┘
                             │
                             │ Cat5e 2 (length TBM): Outbound Pair (Blue / White-Blue)
                             ▼
┌─────────────────────────────────────────────────────────┐
│            NODE 0x03: TREATED WATER TANK (TWT)          │  (Slave Node 0x03 - Roof Top)
│  - Arduino Nano + XY-485 Module                         │
│  - AJ-SR04M Waterproof Ultrasonic Sensor               │
└────────────────────────────┬────────────────────────────┘
                             │
                             │ Cat5e 3 (length TBM): Roof-to-roof Outbound Pair
                             ▼
┌─────────────────────────────────────────────────────────┐
│              NODE 0x02: RAW WATER TANK (RWT)            │  (Slave Node 0x02 - Roof Top)
│  - Arduino Nano + XY-485 Module                         │
│  - AJ-SR04M Waterproof Ultrasonic Sensor               │
│  - NO TERMINATION RESISTOR (WIRING.md 12.3)             │
└─────────────────────────────────────────────────────────┘

-------------------------------------------------------------------------------
2. GROUND FLOOR PARKING SUBSYSTEM (WIRELESS WI-FI LAN TO ESP32 HUB)
-------------------------------------------------------------------------------

Communication: Direct Wi-Fi LAN / mDNS (ro-hub.local) / HTTP REST JSON Push / UDP

┌─────────────────────────────────────────────────────────────────────────────┐
│                 ESP32 NODE 1: SUMP LEVEL MEASUREMENT                        │
│  - Location: Ground Floor Parking (Sump Manhole)                            │
│  - Power: Hi-Link HLK-20M5 (240V AC -> 5V DC 4A)                            │
│  - Microcontroller: ESP32-WROOM-32 / ESP32-C3                               │
│  - Sensor: AJ-SR04M Waterproof Ultrasonic Sensor (3.5m Deep Sump)          │
│  - Role: Telemetry push of Sump Distance (mm), Level (%), and Status        │
└──────────────────────────────────────┬──────────────────────────────────────┘
                                       │
                                       │ (Local Wi-Fi Network - Same LAN)
                                       ▼
                             [ ESP32 CENTRAL HUB ]
                                       ▲
                                       │ (Local Wi-Fi Network - Same LAN)
                                       │
┌──────────────────────────────────────┴──────────────────────────────────────┐
│            ESP32 NODE 2: MOTOR MONITORING & INTERLOCK CONTROL               │
│  - Location: Ground Floor Motor Starter Panel                               │
│  - Power: Hi-Link HLK-20M5 (240V AC -> 5V DC 4A)                            │
│  - Microcontroller: ESP32-WROOM-32 / ESP32-C3                               │
│  - AC Optocoupler 1: Sump Motor Active Monitoring (240V AC Coil)            │
│  - AC Optocoupler 2: Borewell Motor Active Monitoring (240V AC Coil)        │
│  - 4-Channel Relay Module: Dry Contact Emulation                            │
│      * Relay 1: Sump Low-Level Float Cutoff (Sump Motor Protection)         │
│      * Relay 2: Sump High-Level Float Cutoff (Borewell Motor Protection)    │
│      * Relays 3 & 4: Auxiliary / Manual Starter Overrides                   │
└─────────────────────────────────────────────────────────────────────────────┘

===============================================================================

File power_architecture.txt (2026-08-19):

230V AC
   │
   ▼
HLK-20M12
   │
   └── 12V DC
        │
        ├── HUB
        │    └── 5V buck
        │         ├── ESP32
        │         ├── SHT30
        │         ├── RS485
        │         └── sensors
        │
        ├── CAT5e → Tank Node 1
        │             └── 5V buck
        │                  ├── Arduino Nano
        │                  ├── ultrasonic
        │                  └── RS485
        │
        ├── CAT5e → Tank Node 2
        │             └── 5V buck
        │
        └── CAT5e → Tank Node 3
                      └── 5V buck

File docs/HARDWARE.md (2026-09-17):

# Hardware Specifications & Pin Allocations

**Document Version:** 2.1  
**Date:** 2026-08-25  
**System Architecture:** ESP32 HUB (Master) + 4x RS485 Arduino Nano Nodes + 2x Ground Floor Wi-Fi ESP32 Nodes  
**RS485 chain order:** `0x00 HUB -> 0x04 BATTERY ROOM -> 0x03 TWT -> 0x02 RWT` (**no terminators anywhere** — `WIRING.md` §12.3). Address `0x01` retired — the dosing sensor is wired direct to the hub (`WIRING.md` §13)  
**Node platforms:** `0x02`/`0x03` Arduino Nano, **`0x04` Arduino Pro Mini 5V/16MHz** (`WIRING.md` 10.1)

> **Pin allocation authority:** Section 3.1 below is kept identical to `WIRING.md` Section 1, which describes the hub as physically built. `WIRING.md` wins on conflict — this table is corrected to match it, never the reverse (phase-B spec §3.5 / §9). Aster terminal contact polarity and the `ALARM` output are specified in `WIRING.md` Section 6; read it before wiring anything to the controller.
>
> **Corrected 2026-08-25:** this table previously listed `GPIO 33 IN_RWT_FLOT`, an `IN_DOS_LVL` channel, `GPIO 27` as an input, and an 8-channel PC817 board. None of those exist on the built hub.

---

## 1. System Topology Overview

```
 [NO TERMINATOR - WIRING.md 12.3]
┌────────────────────┐
│  ESP32-S HUB (0x00)│ (RO Room Bus Master)
│   XY-485 Master    │
│ + AJ-SR04M direct │ (Dosing tank, ~1 m - no node, see WIRING.md 13)
└─────────┬──────────┘
          │ Cat5e 1: Outbound Pair (Pins 4 & 5: Blue / White-Blue - length TBM)
          ▼
┌────────────────────┐
│BATTERY ROOM (0x04) │ (Battery Room - SHT30 Climate & Exhaust Fan)
│  Pro Mini 5V/16MHz │  NO termination resistor - mid-chain
└─────────┬──────────┘
          │
          │ Cat5e 2: Outbound Pair (Pins 4 & 5: Blue / White-Blue - length TBM)
          ▼
┌────────────────────┐
│  TWT NODE (0x03)   │ (Roof Top - Treated Water Tank)
│    XY-485 Auto     │
└─────────┬──────────┘
          │
          │ Cat5e 3: Roof-to-roof Outbound Pair (length TBM)
          ▼
┌────────────────────┐
│  RWT NODE (0x02)   │ (Roof Top - Raw Water Tank)
│    XY-485 Auto     │
│  NO TERMINATOR     │  END OF BUS
└────────────────────┘

========================================================================================
GROUND FLOOR SUBSYSTEM (WI-FI LAN, POLLED BY THE HUB) - MONITORING ONLY, NO RELAYS
========================================================================================
┌───────────────────────────────┐        ┌─────────────────────────────────────────┐
│     ESP32 NODE 1 (0x05)       │        │           ESP32 NODE 2 (0x06)           │
│  - Sump Level: ultrasonic OR  │        │  - Borewell + sump motor CT clamps      │
│    4-20 mA loop (J-LOOP)      │        │    (6 channels, 5 fitted, 1 empty)      │
│  - AJ-SR04M Sensor            │        │  - Astero PUMP ON dry contact (sump)    │
│  - 230V -> 12V module -> buck │        │  - RWT floaty opto (after metering)     │
│    -> 5V (loop needs the 12V) │        │  - SHT30 (utility room temp/RH)         │
│                                │        │  - Hi-Link HLK-20M5 (5V DC)             │
└───────────────────────────────┘        └─────────────────────────────────────────┘
```

**No relay board on either node.** This subsystem only reads the ground
floor; it does not switch anything. The 4-channel relay interlock design
this document described until 2026-09-08 was never built — see §3.5.

---

## 2. Complete Bill of Materials (BOM)

| Item Description | Model / SKU | Qty | Location / Role |
| :--- | :--- | :---: | :--- |
| **Main RO Bus Power Supply** | Hi-Link `HLK-20M12` (12V / 20W / 1.6A) | 1 | RO Room - Master 12V DC RS485 bus power |
| **Ground Floor Power Supplies**| Hi-Link `HLK-20M5` (5V / 20W / 4.0A) | 1 | Ground Floor - **Node 2 (Utility, `0x06`) only.** Node 1 (Sump, `0x05`) needs 12 V for its `J-LOOP` transducer provision and runs 230V → 12V module → buck → 5V instead — `WIRING.md` §11.1 |
| **Auxiliary Supply** | Hi-Link `HLK-10M05` (5V / 10W / 2.0A) | 1 | Spare / Local 5V high-current logic rail |
| **RS485 Transceiver** | `XY-485` (Auto-Flow Control) | 4 | Hardware auto TX/RX direction switching (1x Hub, 3x slave nodes) |
| **Current Clamp** | `SCT-013-030` split-core CT, 30 A / 1 V output | 8 | 1x HPP + 1x RWP on the hub (`WIRING.md` §14; nameplates in §14.5 — RWP is 6.2 A max, so 3 turns), then **3 phases each** on the ground-floor sump and borewell motors (§11.3). Voltage-output variant: burden resistor is inside, do not add one. Sump and borewell have **no readable nameplate** (submersible, confirmed 2026-08-27) — size from the starter overload dial and a clamp meter, and expect to need 2-3 turns for resolution (`WIRING.md` §11.3.1) |
| **220V AC Opto Isolator** | 1-Channel 220V AC Optocoupler Module | 2 | RO Room (HPP/RWP) only. **The ground floor has none** — its motors are read by CT clamps and the Astero `PUMP ON` dry contact, not by sensing the contactor coil (`WIRING.md` §11.2). A DC optocoupler for the ground floor's `RWT FLOTY` loop is a separate part, added only if metering that loop finds low-voltage DC (§11.4) — **a 5th of this AC part** is still needed only if the Aster `ALARM` output measures as switched mains — see `WIRING.md` 6.4 |
| **DC Dry-Contact Opto** | 4-Channel PC817 Optocoupler Board | 1 | RO Room - Aster controller dry switch isolation. **As-built part**; all 4 channels used: `RL1`, `RL2`, `LPS`, `TWT FLOTY`. `IN_ALARM` needed no optocoupler and moved to a direct input on GPIO 13, which freed channel 3 for `LPS` (`WIRING.md` §6.6). **An 8-channel PC817 board is already owned and unused** (order 2026-08-16) — the 4-channel one was fitted because it was to hand, so extra taps need no purchase, only a rewire. See §0.4 of `WIRING.md` for why pins, not channels, are now the limit |
| **Relay Modules** | 4-Channel 5V Relay Board | 1 | RO Room (Aster Float Emulation) only. **No relay board on the ground floor** — the interlock design once specified for node `0x06` (§3.5) was never built and is out of scope for this round (`WIRING.md` §11) |
| **Relay Module (Single)** | 1-Channel 5V Relay Board | 1 | Battery Room (Exhaust Fan Switching) |
| **Ultrasonic Sensors** | Waterproof Ultrasonic (**AJ-SR04M**) | 4 | **Dosing (wired direct to hub)**, RWT (`0x02`), TWT (`0x03`), Ground Sump (`0x05`). Confirm `R19` mode pad is empty (Trig/Echo mode) — `WIRING.md` §9.0 |
| **Resistors** | 1 kΩ + 1.8 kΩ (1/4 W) | 2 pairs | `ECHO` 5V→3.3V dividers: hub dosing sensor + ground-floor sump sensor. **1.8 kΩ as built**, not the 2 kΩ originally specified — `WIRING.md` §1, §13 |
| **Environmental Sensors** | GY-SHT30-D Digital Temp & Humidity | 2 | 1x RO Room (Hub I2C) + 1x Battery Room (Node 4 I2C) |
| **Ambient Light Sensor** | 7Semi OPT3004 Digital Ambient Light breakout (I2C, Qwiic) | 1 | RWT node `0x02`, `A4`/`A5`, address `0x45`. Faces the sky; drives **Dark Outside** for the building lights via Alexa — `WIRING.md` §9.6, `RS485_PROTOCOL.md` §4.6 |
| **Microcontrollers** | ESP32-WROOM-32 DevKit — **record pins-per-side AND row pitch before reordering** (TODO: measure the hub's socket) | 3 | 1x Central Hub + 2x Ground Floor Nodes. **Pin count alone is not enough to order by** — ESP32 DevKits ship in several row pitches (commonly 0.9" and 1.0", some 1.1") with identical pin counts and identical labels, and listings rarely state which. A wrong-pitch board arrives looking correct and will not seat. Count the perfboard holes between the two socket rows and order to that number (`WIRING.md` §0.3.1) — cost a wasted purchase 2026-09-03 |
| **Microcontrollers** | Arduino Nano (ATmega328P) | 2 | RS485 Slave Nodes `0x02`, `0x03` |
| **Microcontrollers** | Arduino Pro Mini (ATmega328P-AU, **5V / 16 MHz**) | 1 | RS485 Slave Node `0x04` Battery Room. Needs an FTDI/CP2102 adapter to program — see `WIRING.md` 10.1 |

---

## 3. Pin Allocations by Subsystem

### 3.1. ESP32-S Central Hub Pin Allocations (RO Room)
| ESP32 GPIO | Pin Function | Connected Hardware / Circuit | Direction | Interface Notes |
| :--- | :--- | :--- | :--- | :--- |
| **GPIO 16** | `RS485_RX` | XY-485 Module `RXD` | Input | 3.3V UART2 RX |
| **GPIO 17** | `RS485_TX` | XY-485 Module `TXD` | Output | 3.3V UART2 TX |
| **GPIO 21** | `I2C_SDA` | GY-SHT30-D `SDA` (RO Room) | Bidirectional | I2C SDA (4.7kΩ pull-up to 3.3V) |
| **GPIO 22** | `I2C_SCL` | GY-SHT30-D `SCL` (RO Room) | Output | I2C SCL (100kHz standard) |
| **GPIO 34** | `IN_HPP_AC` | 220V AC Optocoupler Module 1 `OUT` | Input | Active LOW when HPP 240V contactor active. Onboard 47 k pull-up to `VCC`; wire `VCC` to 3V3 |
| **GPIO 35** | `IN_RWP_AC` | 220V AC Optocoupler Module 2 `OUT` | Input | Active LOW when RWP 240V active. Onboard 47 k pull-up to `VCC`; wire `VCC` to 3V3 |
| **GPIO 32** | `IN_TWT_FLOT` | 4-Ch PC817 Board Ch 4 `V4` | Input | Aster `TWT FLOTY` loop. LOW = closed = tank not full |
| **GPIO 26** | `IN_RL1_STAT` | 4-Ch PC817 Board Ch 1 `V1` | Input | Aster RL1 contact. LOW = closed = output active |
| **GPIO 25** | `IN_RL2_STAT` | 4-Ch PC817 Board Ch 2 `V2` | Input | Aster RL2 contact. LOW = closed = output active |
| **GPIO 33** | `IN_LPS` | 4-Ch PC817 Board Ch 3 `V3` | Input | Aster `LPS` low-pressure contact, `C`/`NO`. Took this channel from `IN_ALARM` on 2026-08-27 |
| **GPIO 13** | `IN_ALARM` | Aster `AUX OP` relay `C`/`NO`, **direct** | Input | No optocoupler, no external parts — the relay contact is already the isolation barrier and the relay is enclosed. `INPUT_PULLUP`, debounced 6-of-8 in firmware (`WIRING.md` §6.6) |
| **GPIO 36** | `IN_HPP_CT` | SCT-013-030 clamp (HPP) | Input | Analog, ADC1_CH0. Motor current for health trending — spec §7.3 |
| **GPIO 39** | `IN_RWP_CT` | SCT-013-030 clamp (RWP) | Input | Analog, ADC1_CH3. Motor current for health trending — spec §7.3 |
| **GPIO 27** | `OUT_RLY_TWT` | 4-Ch Relay Module IN1 | Output | TWT Float Switch Emulation (`COM`/`NC`, de-energized = closed). Phase C |
| **GPIO 23** | `OUT_RLY_RWT` | 4-Ch Relay Module IN2 | Output | RWT Float Switch Emulation (`COM`/`NC`, de-energized = closed). Phase C |
| **GPIO 18** | `OUT_RLY_DOS` | 4-Ch Relay Module IN3 | Output | Dosing Level Switch Emulation (`COM`/`NC`, de-energized = closed). Phase C |
| **GPIO 19** | `OUT_RLY_AUX` | 4-Ch Relay Module IN4 | Output | Auxiliary / interlock override. Polarity depends on target terminal (`WIRING.md` 7.2). Phase C |
| **GPIO 5** | `US_TRIG_DOS` | AJ-SR04M (Dosing) `TRIG` | Output | 10 µs trigger. Sensor wired direct to hub (`WIRING.md` §13) |
| **GPIO 4** | `US_ECHO_DOS` | AJ-SR04M (Dosing) `ECHO` | Input | Echo width. **1 kΩ/1.8 kΩ divider as built** (5V→3.21V) |
| **GPIO 2** | `LED_STATUS` | System Heartbeat LED | Output | Active HIGH onboard LED |
| **GPIO 0** | `BTN_BOOT` | Onboard BOOT Button | Input | Factory reset / provisioning trigger |

**Constraints:** GPIO 34-39 have no internal pull-up, but the AC opto module supplies a 47 k pull-up from `OUT` to `VCC` (**corrected 2026-08-27** — `WIRING.md` §1), so 34 and 35 need no external resistor, only `VCC` on 3V3. The four open-collector PC817 channels sit on pull-up-capable pins (25/26/32/33). GPIO 6-11 are flash, 1/3 are the serial console. **Updated 2026-08-27:** 4/5 went to the dosing ultrasonic and **13 now carries `IN_ALARM` directly** (§6.6), so of what is left **12 and 15 are strapping pins** — 12 selects flash voltage at boot — which leaves **GPIO 14 as the last comfortable spare on this board**.

---

### 3.2. Arduino Nano Tank Nodes Pin Allocations (Nodes 0x02, 0x03)
| Nano Pin | Pin Function | Connected Hardware | Direction | Notes |
| :--- | :--- | :--- | :--- | :--- |
| **D2** | `RS485_RX` | XY-485 Module `RXD` | Input | SoftwareSerial RX |
| **D3** | `RS485_TX` | XY-485 Module `TXD` | Output | SoftwareSerial TX |
| **D7** | `US_TRIG` | AJ-SR04M Sensor `TRIG` | Output | 10µs trigger pulse |
| **D8** | `US_ECHO` | AJ-SR04M Sensor `ECHO` | Input | Echo pulse width |
| **A0** | `ADDR_SEL0` | Hardware Node Address Bit 0 | Input | `INPUT_PULLUP`: open = 1, GND = 0. `ADDR_MAP` lookup: `WIRING.md` §9.1 |
| **A1** | `ADDR_SEL1` | Hardware Node Address Bit 1 | Input | `0x02` = A0 GND. `0x03` = A1 GND. `0x04` = both open. Both GND = unassigned |
| **D13** | `LED_STATUS` | Status / RS485 Activity | Output | Blinks on successful poll |

---

### 3.3. Arduino Pro Mini Battery Room Node (Node 0x04)

Built on a **Pro Mini (5V / 16 MHz)**, not a Nano. Pin functions are identical — same ATmega328P, same firmware binary — but the power feed, the `A4`/`A5` breakout and programming differ. Build notes: `WIRING.md` 10.1.

| Pro Mini Pin | Pin Function | Connected Hardware | Direction | Notes |
| :--- | :--- | :--- | :--- | :--- |
| **VCC** | `+5V_IN` | Mini560 / LM2596 buck `VOUT+` | Power In | **Feed here, not `RAW`.** `RAW` routes through a SOT-23 LDO that cannot dissipate 12V→5V at this node's load |
| **D2** | `RS485_RX` | XY-485 Module `RXD` | Input | SoftwareSerial RX. `D0`/`D1` stay free for the FTDI header |
| **D3** | `RS485_TX` | XY-485 Module `TXD` | Output | SoftwareSerial TX |
| **A4** | `I2C_SDA` | GY-SHT30-D `SDA` | Bidirectional | Hardware I2C SDA (`PC4`). **Inner pad — not on the edge header** |
| **A5** | `I2C_SCL` | GY-SHT30-D `SCL` | Output | Hardware I2C SCL (`PC5`). **Inner pad — not on the edge header** |
| **D9** | `OUT_FAN_RLY` | 1-Channel Relay Board `IN` | Output | Active LOW Exhaust Fan control |
| **D13** | `LED_STATUS` | Onboard LED | Output | Heartbeat indicator |
| **A0 / A1** | `ADDR_SEL0/1` | Address jumpers | Input | **`0x04` = both left unconnected** (as-built). Leave both pads open — `WIRING.md` §9.1 |
| **DTR / TXO / RXI** | Programming | FTDI / CP2102 adapter (5V) | — | `DTR` must be wired or uploads time out. Disconnect the buck 5V while the adapter is attached |

---

### 3.4. Ground Floor ESP32 Node 1: Sump Telemetry (0x05)
| ESP32 GPIO | Pin Function | Connected Hardware | Direction | Notes |
| :--- | :--- | :--- | :--- | :--- |
| **GPIO 5** | `US_TRIG` | AJ-SR04M Sensor `TRIG` | Output | 10µs ultrasonic trigger |
| **GPIO 18** | `US_ECHO` | AJ-SR04M Sensor `ECHO` | Input | 5V $\to$ 3.3V resistor voltage divider (1kΩ/2kΩ) |
| **GPIO 34** | `LOOP_SENSE` | `J-LOOP` pin 2, 4-20 mA loop sense | Input | Analog, ADC1_CH6. 0 when no transducer is fitted — `WIRING.md` §11.1, §9.4.2 |
| **GPIO 25** | `PRESS_FIT` | `J-PRESS` shunt to GND | Input, pull-up | Shunt fitted = pressure transducer is the source; off = ultrasonic — `WIRING.md` §11.1 |

---

### 3.5. Ground Floor ESP32 Node 2: Utility Room Monitoring (0x06)

**Corrected 2026-09-08: this table described a 4-channel relay board doing
starter interlocks. That node was never built that way — it only reads the
panel; nothing here switches anything, and the relay interlock idea stays a
Phase-2 option, out of scope for this round (`WIRING.md` §11).** Two of the
four GPIOs this table used to list as relay outputs, 25 and 26, are real
inputs on the built node — the Astero `PUMP ON` contact and the RWT floaty
opto — so wiring this table as printed would have driven a relay coil into
what is actually a sensor input.

| ESP32 GPIO | Pin Function | Connected Hardware | Direction | Notes |
| :--- | :--- | :--- | :--- | :--- |
| **GPIO 32** | `BORE_CT_L1` | SCT-013-030 clamp | Input | Analog, ADC1_CH4. Borewell phase L1 — `WIRING.md` §11.3 |
| **GPIO 33** | `BORE_CT_L2` | SCT-013-030 clamp | Input | Analog, ADC1_CH5. Borewell phase L2 |
| **GPIO 34** | `BORE_CT_L3` | SCT-013-030 clamp | Input | Analog, ADC1_CH6. Borewell phase L3 |
| **GPIO 35** | `SUMP_CT_L1` | SCT-013-030 clamp | Input | Analog, ADC1_CH7. Sump motor phase L1 |
| **GPIO 36** | `SUMP_CT_L2` | SCT-013-030 clamp | Input | Analog, ADC1_CH0. Sump motor phase L2 |
| **GPIO 39** | `SUMP_CT_L3` | SCT-013-030 clamp | Input | Analog, ADC1_CH3. Sump motor phase L3 — socket built, no clamp fitted yet |
| **GPIO 25** | `PUMP_ON` | Astero `PUMP ON (C, NO)` dry contact | Input, pull-up | Sump-motor run signal, wired like the hub's own `IN_ALARM` — `WIRING.md` §11.2, §11.4 |
| **GPIO 26** | `RWT_FLOTY` | Astero `TWT FLOTY` terminal, via opto | Input, pull-up | Only after metering the loop — mains potential is never tapped — `WIRING.md` §11.2, §11.4 |
| **GPIO 21** | `I2C_SDA` | GY-SHT30-D `SDA` | Bidirectional | Utility room temperature/humidity |
| **GPIO 22** | `I2C_SCL` | GY-SHT30-D `SCL` | Output | I2C SCL |

**No status LED on either ground-floor node.** Both tables listed `GPIO 2` as a
Wi-Fi heartbeat LED; `firmware/gf_node/main/gf.h` defines no such pin and no
node source drives one, so the row was documentation of a feature that does not
exist — exactly the documented-but-unread shape `docs/check_pinmap.py` now fails
on for these two tables. Liveness is read from the hub's node list, or directly
from `GET /` on the node, which prints its role, id and firmware.

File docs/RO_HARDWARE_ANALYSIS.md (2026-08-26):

# RO Plant Hardware Analysis

**Document Version:** 1.1  
**Date:** 2026-08-25  
**Source Evidence:** 19 High-Resolution Photographs in `/images`, plus the Aster NXT manual `docs/ASTERO-NXTG-1_opt.pdf`

> **v1.1 corrections (2026-08-25):** `LPS` is silkscreened `C`/`NO`, not `C`/`NC`. `HPS` reads open-circuit as *normal*, not as a fault, and is unwired on this plant. The `ALARM` terminal is the panel's configurable `AUX OP`, not a dedicated alarm relay. Contact polarity is now specified in one place — `WIRING.md` Section 6 — and this document defers to it.

---

## 1. Executive Summary

This analysis provides an evidence-based breakdown of the existing Reverse Osmosis (RO) plant electrical, electronic, and mechanical systems. Every finding is backed by physical photographic evidence from the `images/` directory.

The system is controlled by an **Aster NXT 11** embedded controller built on the **ASTERO-LTE-CPU-22-VER-1.5** PCB, accompanied by an **Initiative Engineering Multiport Valve Controller**, a **TC Contactor TCDP302** high-current motor starter, flowmeters, and sensor transducers.

---

## 2. Image-by-Image Photographic Observations

| Image Filename | Primary Subject | Detailed Photographic Observations |
| :--- | :--- | :--- |
| `IMG_2836.JPG` | Front Panel Overview | Stainless steel skid panel showing the **Aster NXT 11** controller LCD interface (displaying "* SYSTEM FULL !! *"), system status LED indicators, pressure gauges, and vertical flow rotameters. |
| `IMG_2837.JPG` | Enclosure Side/Rear | Controller housing enclosure mounting, external conduit entry, and stainless steel structural frame. |
| `IMG_3372.JPG` | Internal Enclosure | High-voltage compartment: heavy gauge AC wiring, contactor assembly, terminal junction blocks, and AC-to-DC / filtering modules. |
| `IMG_3373.PNG` | Power Junction & Fuses | Close-up of internal AC terminal blocks, auxiliary wiring harnesses, and grounding points. |
| `IMG_3375.PNG` | Control Board Wiring | PCB ribbon cables connecting display panel to the main I/O board, screw terminal landings with blue, black, and red signal wiring. |
| `IMG_3383.JPG` | CPU Board Overview | Full PCB view of **ASTERO-LTE-CPU-22-VER-1.5** showing relay bank (RL1, RL2, ALARM), digital input headers, op-amp signal conditioning, and microcontroller circuitry. |
| `IMG_3384.JPG` | Terminal Markings | Close-up macro of green pluggable terminal blocks showing markings: `HPS`, `LPS`, `TWT FLOTY`, `RWT FLOTY`, `DOS LVL`, `RL1`, `RL2`. |
| `IMG_3385.JPG` | Board Nomenclature & Relays | Clear view of silkscreen label `ASTERO-LTE-CPU-22-VER-1.5`, Hongfa `HF3FF-012-1ZST` 12VDC relays, and barcode label `NXC2509GB018`. |
| `IMG_3389.JPG` | Sensor & Pulse Terminals | Macro shot showing bottom terminal blocks: `COND` (Conductivity probe), `PULSE O/P`, `FLOW 1`, `FLOW 2` (terminals marked with signal, ground, +). |
| `IMG_3395.JPG` | RO Skid Wide View | Full view of skid assembly: **Aster NXT 11** controller, **Alfa Aerosol** certified FRP pressure vessel (NSF/ANSI/CAN-61), and stainless steel pipework. |
| `IMG_3396.JPG` | Flowmeter (Rotameter) | **Aster F-1200 LG** rotameter rated 200–1200 LPH (4–20 LPM) with red float indicating flow rate. |
| `IMG_3399.JPG` | Main PCB & Terminal Block (Top View) | Comprehensive top view of `ASTERO-LTE-CPU-22-VER-1.5` showing relay outputs, dry contact sensor inputs, optocoupler isolators, and analog sections. |
| `IMG_3400.JPG` | PCB Component Layout | Detailed view of IC footprint `IC1`, resistor divider network (`R14`–`R21`, `RN1`), jumper blocks (`J15`, `J16`), and power rail filtering. |
| `IMG_3408.JPG` | Multiport Valve Display | **Initiative Engineering** automated multiport valve controller LCD displaying `* FILTER * BACKWASH TIME : 05` with membrane keypad. |
| `IMG_3409.PNG` | Power & Driver ICs | Close-up of **LM7805** (TO-220 5V linear regulator with heatsink nut), **ULN2003AN** (7-channel Darlington relay driver array), and `HF3FF 012-1ZST` relays (10A 250VAC / 10A 277VAC). |
| `IMG_3410.PNG` | Analog & Charge Pump Section | High-magnification shot showing **LM324L** (Quad operational amplifier for conductivity / analog front-end) and **TC7660** (Charge Pump DC-to-DC voltage converter for negative rail generation in AC conductivity sensing). |
| `IMG_3411.PNG` | Motor Contactor | **TC Contactor TCDP302** Definite Purpose Contactor (Rating: 600V max, FLA 30A, LRA 150A, 1-Phase 120V 2HP / 240V 3HP, UL/CSA/CE certified). |
| `IMG_3414.PNG` | Mains Power/Filter Board | Dedicated input protection board featuring `BLX-A` fuse holder, blue MOV varistor, green toroidal common-mode choke inductor, yellow X2 suppression capacitors, and screw terminal blocks. |
| `IMG_3416.PNG` | Contactor Coil Terminals | Close-up of contactor coil rating **240V 50Hz** with terminal `A2` having green/blue lead connected via spade connector. |

---

## 3. Identified System Equipment

### 3.1. Main Controller: Aster NXT 11
- **PCB Model:** `ASTERO-LTE-CPU-22-VER-1.5`
- **Sub-components:**
  - Microcontroller / CPU core (IC1 DIP footprint / sub-module)
  - **LM7805** linear regulator for internal 5V logic supply
  - **ULN2003AN** relay driver IC
  - **LM324L** quad op-amp (used for conductivity signal amplification and filtering)
  - **TC7660** charge pump inverter (used to provide bipolar voltage excitation for conductivity probes to prevent electrode polarization)
  - 3x **Hongfa HF3FF-012-1ZST** power relays (12VDC coil, 10A @ 250VAC switching capacity)
  - Input protection and resistor array networks (`RN1`, `R14`–`R21`)

### 3.2. Motor Starter Contactor
- **Model:** TC Contactor `TCDP302`
- **Coil Voltage:** 240V AC 50Hz (terminals A1 / A2)
- **Power Contacts:** Single/Dual-pole contactor rated up to 30A Full Load Amps (FLA), 150A Locked Rotor Amps (LRA), suitable for driving the High Pressure Pump (HPP) motor (2–3 HP @ 240VAC).

### 3.3. Filter Backwash Controller
- **Manufacturer:** Initiative Engineering
- **Function:** Automated media filter backwash valve controller with timer functionality (`* FILTER * BACKWASH TIME : 05`).

### 3.4. Hydraulic & Filtration System
- **Membrane Housing:** Alfa Aerosol Pressure Vessels (Certified to NSF/ANSI/CAN-61)
- **Rotameter:** Aster F-1200 LG (Scale: 200 – 1200 LPH / 4 – 20 LPM)

---

## 4. Identified PCB Terminal Blocks & Pinout (ASTERO-LTE-CPU-22-VER-1.5)

Based on direct inspection of `IMG_2836.JPG`, `IMG_3384.JPG`, `IMG_3385.JPG`, `IMG_3389.JPG`, `IMG_3399.JPG`, and `IMG_3400.JPG`, the primary terminal blocks are mapped as follows:

```
┌─────────────────────────────────────────────────────────────┐
│           ASTERO-LTE-CPU-22-VER-1.5 TERMINAL BLOCKS         │
├─────────────────────────────────────────────────────────────┤
│ Upper-Right Block (Aux Output / Solenoid):                  │
│   [ ALARM     ]  C   | NO    (AUX OP relay - CONFIGURABLE)  │
│   [ RSV       ]  ...         (Reject Solenoid Valve output) │
├─────────────────────────────────────────────────────────────┤
│ Main Block (silkscreen order, left to right):               │
│   [ RL1       ]  C   | NO    (Relay 1 Output - HPP / MPV)   │
│   [ RL2       ]  C   | NO    (Relay 2 Output - RWP / MPV)   │
│   [ DOS LVL   ]  C   | NC    (Dosing Tank Level Switch)     │
│   [ RWT FLOTY ]  C   | NC    (Raw Water Tank Float)         │
│   [ TWT FLOTY ]  C   | NC    (Treated Water Tank Float)     │
│   [ LPS       ]  C   | NO    (Low Pressure Switch)          │
│   [ HPS       ]  C   | NO    (High Pressure Sw - UNWIRED)   │
├─────────────────────────────────────────────────────────────┤
│ Flow Sensor Block:                                          │
│   [ FLOW 1    ]  R   | G   | B  (+5V / Signal / GND)        │
│   [ FLOW 2    ]  ...                                        │
├─────────────────────────────────────────────────────────────┤
│ Bottom Section:                                             │
│   [ COND      ]  Probe Terminal 1 | Probe Terminal 2        │
│   [ PULSE O/P ]  Pulse Output Terminal                      │
└─────────────────────────────────────────────────────────────┘
```

---

## 5. Candidate vs. Confirmed vs. Unknown Signals

### 5.1. Confirmed Signals (Physical Evidence Verified)
1. **HPS (High Pressure Switch Input):** Dry contact input, marked `C` / `NO`. **Open circuit is the normal state** (setpoint sits above operating pressure, so the switch only closes on over-pressure). Unwired on this plant, which is why the plant runs with nothing landed on it.
2. **LPS (Low Pressure Switch Input):** Dry contact input, marked `C` / `NO` — **corrected in v1.1, this was previously recorded as `NC`**. The switch closes once feed pressure exceeds its setpoint, so the loop is **closed while running**; an open loop reads as `LOW PRESSURE!!` (manual p.12).
3. **TWT FLOTY (Treated Water Tank Float):** Switch input marked `C` and `NC`.
4. **RWT FLOTY (Raw Water Tank Float):** Switch input marked `C` and `NC`.
5. **DOS LVL (Dosing Level Switch):** Switch input marked `C` and `NC`.
6. **RL1 Output:** Relay 1 dry contact `C` / `NO` (switches contactor coil / pump power).
7. **RL2 Output:** Relay 2 dry contact `C` / `NO` (switches raw water pump or auxiliary solenoid).
7a. **ALARM Output:** the panel's `AUX OP` — volt-free `C` / `NO` pair of the third `HF3FF-012-1ZST`, sited between the relay bank and `RSV`. Configurable in firmware as `ALARM` / `DOSING PUMP` / `PMP ON` (password 678), so **the terminal name does not guarantee the function**. See `WIRING.md` 6.3.
8. **Contactor Coil Control (HPP):** 240V AC 50Hz on contactor A1/A2 coil.
9. **FLOW 1 / FLOW 2:** Flow sensor pulse inputs.
10. **COND:** EC/TDS conductivity probe interface with AC excitation.

### 5.2. Candidate Signals (To Be Monitored by ESP32 HUB)
1. **HPP Status (240V AC):** Monitor voltage across contactor coil or pump supply lines using an AC optocoupler module.
2. **RWP Status (240V AC / Relay):** Monitor voltage across RWP feed or RL2 contact using an AC optocoupler module.
3. **TWT Float Status:** Tap into TWT FLOTY terminals via high-impedance opto-isolated dry contact buffer (or read via RS485 Nano node).
4. **RWT Float Status:** Tap into RWT FLOTY or monitor via remote tank Node #2.
5. **Dosing Level Status:** Tap into DOS LVL or monitor via remote tank Node #1 ultrasonic sensor.

### 5.3. Unknown / Unverified Signals (Requiring Multi-meter Check on Site)
1. **Internal Logic Voltage on C (Common) terminals:** Determine whether `C` is tied to +5V, +12V, or GND through internal pull-up resistors. Gates whether our 12V wetting loop (`WIRING.md` 5.2) can be applied to a given pair.
2. **PULSE O/P Electrical Characteristics:** Verify if open-collector NPN or 5V logic pulse.
3. **Communication Header `J16`:** Header pins near CPU marked J16 may be factory programming / UART; currently unverified.
4. ~~**`AUX OP` current setting:** is it `ALARM`, `DOSING PUMP`, or `PMP ON`?~~ **Answered 2026-08-26 by observation:** the pair is open while the plant runs and closes on a plant issue, i.e. `ALARM`. Despite the manual directing `PMP ON` where an auto-MPV is fitted in pretreatment, this panel is not set that way. Unblocks the alarm telemetry channel (`WIRING.md` §6.3).
5. **`HI PRESS SW` enabled or bypassed:** with `HPS` unwired, `ON` means an input watching a switch that can never close; `OFF` means the input is bypassed. Determines whether shorting `HPS` is usable as a commissioning test trigger.

---

## 6. Recommended Interfacing Strategy

### 6.1. High-Voltage Monitoring (HPP & RWP - 240V AC)
- **Technique:** Do **NOT** connect 240V AC directly to ESP32 or any low-voltage logic.
- **Circuit:** Dedicated 240V AC Optocoupler Isolation Board (utilizing PC814 / EL814 bidirectional AC optocouplers or PC817 with bridge rectifier + series safety dropping resistor + RC snubber + pull-up to ESP32 3.3V).
- **Safety Standard:** 3.75kV – 5kV galvanic isolation barrier between mains and ESP32 low-voltage DC logic.

### 6.2. Low-Voltage Switch & Relay Monitoring
- **Technique:** Galvanic opto-isolation (PC817 based) for dry contact inputs so that potential ground loops or fault voltages in the Aster controller do not feed back into the ESP32 Hub.

### 6.3. Remote Tank Levels (Dosing, Raw, Treated)
- **Technique:** Dedicated Arduino Nano nodes located at each tank running AJ-SR04M waterproof ultrasonic sensors, transmitting filtered numeric millimeter levels over daisy-chained RS485 (MAX485 / MAX13487) back to the ESP32 Hub.

---

## 7. Safety Notes & Precautions

1. **Galvanic Isolation is Mandatory:** The controller enclosure houses live 240V AC (50Hz) wiring on the main contactor, relays, and power supply. Mains wires must maintain at least 6mm physical creepage/clearance from all ESP32 SELV wiring.
2. **No Mains Control in Phase 1:** ESP32 HUB operates strictly as a **passive monitoring system**. It does not energize or override pump relays or contactors.
3. **Dedicated Power Supply:** System uses an independent **HLK-20M12** (12V DC / 20W) power supply rather than tapping the Aster board's internal LM7805 regulator.

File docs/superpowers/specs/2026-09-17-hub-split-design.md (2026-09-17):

# Hub split: ESP32-S3 hub on the ground floor, terrace hub becomes a node

Date: 2026-09-17. Status: approved in conversation, awaiting written review.

## 1. Why

The terrace hub (ESP32 DevKit, 4 MB flash, no PSRAM, fw `5368ad3`) runs out of
heap. Measured 2026-09-16 and again after a power cycle: 42–45 KB free at
steady state, `heap_min` under 300 bytes. One mbedTLS session costs ~42 KB at
the default settings and MQTT already holds one, so a RainMaker OTA cannot
open its TLS connection (`mbedtls_ssl_setup -0x7F00`). Every feature added to
the hub in the last month has come out of that same 42 KB.

Flash is not the constraint (14 % of the app partition free). RAM is. A
16 MB ESP32 has the same 520 KB SRAM; a module with PSRAM does not. The
decision is to move the RainMaker / dashboard / storage role to an
ESP32-S3-WROOM-1-N16R8 (16 MB flash, 8 MB octal PSRAM) in the utility room,
and reduce the terrace board to a node that owns the plant's wires.

Decisions taken in the design conversation:

* The S3 is both the new hub and the utility node. The separate utility node
  is cancelled.
* The terrace decides locally for everything that touches a relay or reads the
  RS485 tanks. A LAN outage changes nothing at the plant.
* The current hub is frozen. `4e5aedf` is built but not flashed; no further
  work goes into `hub_prod` as an ESP32 image.
* The S3 carries an SD card for history, read back by the dashboard as
  week / month / year trends.
* The S3 does **not** read the RWT float (§5).

## 2. Roles after the split

```
Terrace (RO room)                       Ground floor (utility room)
ESP32 DevKit on the hub motherboard     ESP32-S3 DevKitC-1 N16R8
firmware/terrace_node                   firmware/hub_prod (target esp32s3)
- RS485 master: 0x02 RWT, 0x03 TWT,     - RainMaker, BLE provisioning, OTA
  0x04 battery room                     - dashboard, /api/*, 24 h RAM history
- dosing ultrasonic (direct)            - SD card: 1-min rows, day ledger
- HPP/RWP AC optos + clamps             - run accounting, day ledger, alerts
- Aster contacts: TWT float, RL1, RL2,  - borewell + sump motor clamps (6 ch)
  LPS, ALARM                            - Astero PUMP ON contact
- relays, relay test                    - utility-room SHT30
- RO-room SHT30, fan policy             - polls: terrace node, sump node
- /cal for tanks, clamps, TDS, fan
- /api/telemetry, POST fan, POST relay
- /ota (raw image over LAN)
                 ^
                 | HTTP GET every 2 s, same as the sump node
                 +---------------------------------------+
```

`gf_node` keeps only the sump role. The utility role moves into the hub.

## 3. Terrace node (`firmware/terrace_node`)

Carved from today's `hub_prod`. Keeps `app_rs485.c`, `app_sensors.c`, the
tank / clamp / TDS / fan parts of `app_cal.c`, and the poll loop's sensor half.
Drops RainMaker, BLE, `dashboard.html`, history, run accounting, the day
ledger, alerts, the cloud watchdog, `esp_rmaker_*` everywhere.

**Network.** Joins the house LAN as a station with credentials in NVS, set
once over serial (the `gf_node` pattern). No AP, no BLE, no mDNS required;
the hub addresses it by IP from its node table. Fixed DHCP reservation on the
router.

**Local decisions kept:**

* Fan policy from battery-room temperature, thresholds and mode in its NVS.
* Relay test pulse and self-expiry.
* The future Relay 1 interlock (float + ultrasonic agreement) belongs here.
  Not part of this project; the split must not make it harder.

**`GET /api/telemetry`** — interpreted values, calibration applied. One
object, keys fixed by the checker in §7:

```
link:     { id: 7, fw, uptime_s, rssi }   (5 = sump, 6 was utility, 0x01 is a retired RS485 address)
tanks:    { rwt|twt|dos: { pct, distance_mm, sensor, online } }
quality:  { rwt|twt: { ppm, t_deci_c, fitted, live, age_s } }
motors:   { hpp|rwp: { running, ac_floating, deci_amps, mv_lo, mv_hi } }
contacts: { twt_float_closed, rl1_active, rl2_active, lps_active, alarm_active }
climate:  { ro_room|battery_room: { temp_deci_c, hum_deci_pct, fault } }
fan:      { on, mode }
rs485:    { errors, last_poll_ms, failures }
```

Missing readings use the same sentinels the hub uses today (`-1`, `null`),
never a plausible zero.

**`POST /api/fan`** body `mode=auto|on|off`. **`POST /api/relay`** body
`idx=N` — one pulse, firmware releases it, no latch (today's `/cal` button).

**`/cal`** — tank distances, TDS k and gating, clamp midpoint and gain for
HPP/RWP, fan thresholds. Same NVS namespace and keys as today, so the reflash
needs no recalibration.

**`POST /ota`** — raw image, copied from `gf_node/main/ota.c` including the
trial-image guard. Image is on trial until one telemetry fetch has been
served, then marked valid within 120 s or rolled back.

**Timing.** Own sensors every 2 s (`POLL_CYCLE_MS`). The JSON is the last
completed cycle; a fetch never blocks on the bus.

## 4. S3 hub (`firmware/hub_prod`, target `esp32s3`)

**Unchanged:** RainMaker node build, device and parameter names, BLE
provisioning, RainMaker OTA, dashboard page and endpoints, run accounting and
day ledger, alerts (including the plant started/stopped pair and the
long-run backstop), the 24 h RAM history, the cloud watchdog, the fan command
path, the reboot-only system service.

**Replaced:** the terrace I/O calls in `poll_task` become one poller,
`terrace_apply()`, shaped like `gf_apply()`: fetch JSON, parse into the
existing `hub_state_t` fields, mark online/offline by the existing miss rule
(`NODE_OFFLINE_MS`, three misses). Fan mode and relay test become forwarded
POSTs to the terrace.

**Moved in:** the utility node's sensor code from `gf_node` — six clamp
channels, PUMP ON contact, SHT30. The `0x06` node entry disappears from the
node list and `/cal`; the sump node `0x05` stays.

**Memory plan.** `CONFIG_SPIRAM=y`, octal mode, `SPIRAM_USE_MALLOC`,
`SPIRAM_TRY_ALLOCATE_WIFI_LWIP`, `MBEDTLS_EXTERNAL_MEM_ALLOC`. Dynamic TLS
buffers stay on. The RAM history ring returns to one-minute rows (1440 × 24 B)
and is allocated in PSRAM. Success criterion: `heap_min` after provisioning
and after an OTA both above 100 KB internal, and the OTA completes.

**Node table.** The utility slot in `/cal` becomes the terrace slot (IP:port); the sump slot stays. Seed fields for
HPP and RWP lifetime seconds (write-once, used at cutover).

**Failure behaviour.** Terrace offline → its dashboard sections hatch, roof
pumps are unobservable to run accounting (no invented stops), alerts hold
their latch, node-offline alert names the terrace. Hub offline → plant runs
as before, no cloud, no dashboard.

## 5. S3 hardware

ESP32-S3-WROOM-1-N16R8 on a DevKitC-1. Octal PSRAM owns GPIO 33–37; GPIO 0,
3, 45, 46 are strapping; 19/20 are USB. ADC2 is unusable with Wi-Fi, so all
clamps sit on ADC1 (GPIO 1–10).

| Function | GPIO | Note |
|---|---|---|
| Borewell clamps L1 L2 L3 | 1, 2, 4 | ADC1 |
| Sump motor clamps L1 L2 L3 | 5, 6, 7 | ADC1 |
| SD card SPI CLK / MOSI / MISO / CS | 12 / 11 / 13 / 14 | SPI2 via GPIO matrix |
| SHT30 SDA / SCL | 17 / 18 | ADC2 pins, free |
| Astero PUMP ON contact | 21 | opto, active low |
| Status LED | 48 | on-board RGB |
| Boot button | 0 | on-board |
| spare ADC1 | 8, 9, 10 | 7th/8th clamp or a loop sensor |
| reserved, unused | 38 | RWT float — see below |

Clamp front end: the utility-node spec in `WIRING.md` (burden, midpoint
divider), attenuation matched to the S3's 3.3 V range. SD module: SPI type
rated for 3.3 V logic, own regulator acceptable.

**RWT float is not read.** The float cable runs ~25 m from the terrace to the
Astero through mains conduit — the same capacitive path that put 18–40 V on
the TWT wires — and an opto across the loop would be a second wetting circuit
sharing the Astero's high-impedance sense contact, the arrangement that
latched the TWT on 2026-09-13. One owner per float contact. The field keeps
its "not wired" sentinel. If ownership is wanted later, it is the TWT plan
mirrored (S3 owns the float with a 3 kΩ / 4 mA loop, drives the Astero input
through a relay) and gets its own design.

## 6. SD card storage and long-range trends

* FAT, SPI mode, mounted once at boot. **Never auto-formatted.** Mount
  failure is logged, shown on the dashboard, and the hub runs without it.
* One binary file per local day, `hist/YYYYMMDD.bin`, rows of the RAM
  history record at one-minute period: ~35 KB/day, ~13 MB/year. Append once a
  minute, `fsync` after each row; a power cut loses at most one row.
* The day ledger stays in NVS (34 days) for the run table, and each midnight
  close is also appended to `ledger.bin` so run figures outlive NVS.
* `GET /api/history?from=<epoch>&to=<epoch>` returns at most 720 points,
  every Nth row across the day files, same row shape as today's endpoint so
  the trend strip code is reused. The 24 h view keeps coming from RAM; the
  card is never in the path of the default page.
* Dashboard: range selector on the trend strip — 24 h, 7 d, 30 d, 1 y.

ponytail: FAT on a removable card is the deliberate ceiling; the module's own
16 MB flash could hold ~8 months in a partition with identical file code if
the connector proves unreliable.

## 7. Verification

* `docs/check_terrace_contract.py` — lifts the terrace's telemetry format
  string and the hub's parser keys, fails on drift (pattern of
  `check_telemetry.py`).
* `check_telemetry.py`, `check_offline_view.py`, `check_alerts.py`,
  `check_run_hours.py` follow their code to the hub tree and keep passing.
* `docs/fake_gf_node.py` gains a terrace shape so the S3 can be soaked on a
  bench without the plant.
* Memory acceptance in §4. OTA acceptance: one RainMaker OTA into the S3
  completes on the bench before cutover.

## 8. Build order and cutover

1. Terrace node firmware on the bench (spare DevKit if available; otherwise
   first flashed at step 5). Test: fake bus replies, fan policy, JSON, `/ota`
   and rollback.
2. S3 hub firmware on the bench against the fake terrace. Provision to
   RainMaker as a new node on the bench.
3. Ground-floor board: clamps, PUMP ON, SHT30, SD, power from the utility-room
   supply. S3 goes live reading the ground floor and polling the sump node
   while the old hub still runs the terrace and the cloud.
4. Soak a week: card filling, `heap_min` steady.
5. Cutover, one visit: read old hub lifetime totals from its telemetry;
   serial-flash `terrace_node` onto the terrace board; enter its address and
   the seed totals in the S3 `/cal`; confirm terrace online and tank levels
   back in RainMaker; remove node DB28 from the account.
6. Back-out = reverse of 5 with the serial cable: flash `4e5aedf` onto the
   terrace board, re-add DB28. Nothing on the ground floor is undone.

## 9. Out of scope

Relay 1 interlock; RWT float ownership; separate utility node (cancelled);
any further work on the ESP32 hub image; slab tariffs.

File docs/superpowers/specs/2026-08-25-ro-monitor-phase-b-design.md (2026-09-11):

# RO-Monitor — Phase B Design: RS485 Ring Completion

**Status:** Draft for review
**Date:** 2026-08-25
**Supersedes:** conflicting sections of `docs/HARDWARE.md`, `docs/RS485_PROTOCOL.md`, `docs/WIRING.md` (corrections listed in §9)

---

## 1. Why this project exists

The stated goal in `plan.txt` is RO plant telemetry. The actual driver, established during design review, is a pump failure:

- The **borewell pump** fills the ground **sump**.
- The **sump motor** lifts water from the sump to the rooftop **Raw Water Tank (RWT)**.
- The sump motor is started by the **RWT float**, wired directly to its starter coil.
- Nothing tells the sump motor about the sump's own level.

When the borewell runs dry and the sump empties while RWT is still below its setpoint, the RWT float keeps the sump motor energised and **the sump motor runs dry**.

The missing logic is:

```
run sump motor  <=>  (RWT below setpoint)  AND  (sump above dry-run level)
```

Telemetry is the instrumentation needed to manage this properly. The dry-run cutoff itself is a hardware change and does not depend on any firmware in this document.

### 1.1 Existing float arrangement (confirmed)

A single sump float already exists, **wired to the borewell starter**, sitting **mid-tank**. It is a *borewell top-up* setpoint.

It cannot be reused for dry-run cutoff, for two independent reasons:

1. **Wrong setpoint.** Mid-tank is a level the sump reaches routinely in healthy operation. Tapping it into the sump motor circuit would stop the sump motor every time the borewell decided to refill.
2. **Circuit coupling.** That contact already sits in the borewell starter's control circuit. Paralleling it into the sump motor circuit couples two control circuits that may not share a neutral — a back-feed path.

**Resolution:** a **new float, lower down, dedicated NC contact**, in series with the RWT float into the sump starter coil. The existing mid-tank float is left entirely untouched.

### 1.2 Target interlock chain

```
RWT float --+-- Sump DRY-RUN float (NC) --+-- ESP32 relay (NC) -- Sump starter coil
            |                             |
       (existing)            (new, Phase C)   (new, Phase C, optional)
```

Every added element is **normally closed** and can only ever *stop* the motor, never start it. De-energised equals today's behaviour. An unplugged ESP32 degrades the system to the current design plus a working dry-run float — never to an unprotected pump.

---

## 2. Scope and build order

**Restructured 2026-08-26 into two site-based phases.** The work is now split by *where it is*, not by what kind of work it is — finish everything on the terrace, then open up the ground floor. Two reasons that is the right cut: each phase is a self-contained system that delivers value on its own, and the two sites need different trades on site at different times.

### Phase 1 — Terrace (RO room, battery room, roof tanks)

| Item | State |
| :--- | :--- |
| Hub `0x00`: ESP32, SHT30, 4-ch PC817 opto, RS485 master | **Built** |
| Dosing tank AJ-SR04M wired direct to hub (§13 of `WIRING.md`) | Built, needs calibration |
| Node `0x02` RWT, node `0x03` TWT — Arduino Nano, one shared binary | **Firmware done, on the bench** |
| Node `0x04` battery room — Pro Mini, SHT30 + fan relay | **Firmware done, on the bench** |
| ~~`GPIO 34` / `GPIO 35` external 10 kΩ pull-ups — outstanding hub defect (§3.5)~~ | **Not a defect — withdrawn 2026-08-27.** Module has an onboard 47 k pull-up (§3.5). Both channels **validated against live contactors 2026-08-27** |
| HPP + RWP current clamps on `GPIO 36` / `GPIO 39` (§7.3, `WIRING.md` §14) | Parts ordered |
| TWT level sensor — ultrasonic ruled out by the wall-adjacent hole (`WIRING.md` §9.3) | **Decision open** |
| Local dashboard served by the hub | To build |

**Phase 1 is done when** all three RS485 nodes answer the hub reliably on the installed cable, every tank reads a calibrated level, the battery room fan runs on hub policy, and the dashboard shows it.

### Phase 2 — Ground floor (sump, borewell, starter panel)

| Item | State |
| :--- | :--- |
| Node `0x05` sump level — sensor choice still open (§7.1) | Later |
| Node `0x06` starter panel — 2 × AC opto, 4-ch relay | Later |
| Sump + borewell current clamps, 2 per motor (§7.3) | Clamps in hand |
| Borewell dry-run detection, observe-only first (§7.2) | Later |
| Dry-run float + interlock chain (§1.2) | **See the carve-out below** |

**Phase 2 is done when** the sump has a level, both ground motors report current and run state, and dry-run detection has run long enough in observe-only mode to earn an interlock.

### 2.1 The one thing that must not wait for its phase

**The dry-run float (§1.1) is ground-floor work that belongs in Phase 1's timeframe.** It needs no firmware, no node and no network — a float, a length of cable and an afternoon of an electrician's time, wired NC in series into the sump starter coil.

Everything else on the ground floor can wait for Phase 2 without consequence. This cannot: it is the *only* thing standing between a dry sump and a burnt sump motor, and the failure it prevents is the reason this project exists (§1). Terrace-first means the pump would otherwise stay unprotected for the entire duration of Phase 1.

**Fit it while Phase 1 is being built.** It is the single highest value-per-rupee item in the whole project, and it is independent of every line of code here.

### 2.2 Deferred beyond both phases

| Item | Why it waits |
| :--- | :--- |
| Aster float / level emulation on the hub's 4-ch relay board | Physically terrace hardware, but it *controls* the plant. It belongs after both phases are proven observing, on the same observe-then-act principle as §7.2 |
| Cloud / push alerts | Optional. The local dashboard is the deliverable; cloud is convenience |

> **Historical labels.** Earlier revisions of this document used phases A-D. The mapping: **A and B → Phase 1**, **C → Phase 2**, **D → §2.2**. Older "(Phase C)" tags elsewhere in the documents mean *deferred*, and where they sit on terrace hardware — the relay emulation rows — they now mean §2.2 rather than the ground floor.

---

## 3. Section 1 — The contract layer

### 3.1 Root cause of the documentation conflicts

Hub and node live in separate Arduino `.ino` folders, which cannot share a header. Protocol constants, GPIO numbers and the address table were copy-pasted between them and drifted. Three live contradictions resulted (§9). Fixing the three symptoms without fixing the structure guarantees a fourth.

### 3.2 Repository structure

```
firmware/
  platformio.ini          # envs: hub, tank_node, native (tests)
  common/
    protocol.h            # frame layout, CRC16, command codes, node addresses
    pinmap_hub.h          # the ONE ESP32 GPIO table
    pinmap_node.h         # the ONE Nano pin table
  hub/src/main.cpp
  node/src/main.cpp
  test/test_protocol.cpp  # runs on PC under the native env
  bringup/                # existing esp32_hub_test + nano_node_test, moved verbatim
```

`common/` is on the include path for every env. Hub and node compile against the *same* frame definition; a protocol change that breaks one side now fails the build instead of failing on the bus.

PlatformIO is chosen over the Arduino IDE specifically because the IDE cannot share a header across sketch folders. The existing test sketches move to `bringup/` unmodified — they remain the right tool for poking hardware.

### 3.3 Wire protocol — resolved

`docs/RS485_PROTOCOL.md` wins over the sketches' XOR scheme. XOR-8 misses burst errors, and contactors switching metres away produce burst errors. A bitwise CRC16 is ten lines.

| Byte | Field | Notes |
| :--- | :--- | :--- |
| 0 | `0xAA` | Preamble |
| 1 | `0x55` | Preamble |
| 2 | `NODE_ADDR` | Master `0x00`, slaves `0x01`–`0x04`, broadcast `0xFF` |
| 3 | `COMMAND` | Bit 7 clear = request, set = response |
| 4 | `PAYLOAD_LEN` | N, 0–32 |
| 5 … 4+N | `PAYLOAD` | |
| 5+N | `CRC16_L` | Modbus CRC-16, poly `0xA001`, init `0xFFFF` |
| 6+N | `CRC16_H` | |

CRC is computed over bytes 2 … 4+N (address through payload). Preamble excluded.

> **Superseded 2026-08-26 by the shipped firmware.** `ro_node` and `esp32_hub_test` compute the CRC over **every byte before it, preamble included** (`RS485_PROTOCOL.md` §2). Both ends agree and `docs/check_frame.py` compiles the two implementations together and fails if they ever diverge — but a third implementation written from this line would not interoperate, so the line is corrected rather than left to be discovered on a bus. Including the preamble costs two bytes of CRC input and removes an offset that has to be right in two places.

### 3.4 Commands

| Code | Name | Direction | Applies to |
| :--- | :--- | :--- | :--- |
| `0x01` | `CMD_PING` | Master → slave | All |
| `0x02` | `CMD_READ_LEVEL` | Master → slave | 0x01, 0x02, 0x03 |
| `0x06` | `CMD_READ_CLIMATE` | Master → slave | 0x04 |
| `0x07` | `CMD_SET_FAN_RELAY` | Master → slave | 0x04 |

**`CMD_READ_LEVEL` response payload — changed from `RS485_PROTOCOL.md` §4.2 (8 bytes):**

| Offset | Type | Field |
| :--- | :--- | :--- |
| 0 | `uint16` | `distance_mm` — median-filtered |
| 2 | `uint16` | `raw_distance_mm` — last instantaneous reading |
| 4 | `uint8` | `sensor_status` |
| 5 | `uint8` | `signal_quality` — 0–100, derived from median spread |
| 6 | `uint16` | `node_uptime_s` |

`level_percent` is **removed from the node payload.** See §4.3.

`sensor_status`: `0 = OK`, `1 = BLIND_ZONE`, `2 = ECHO_TIMEOUT`, `3 = OUT_OF_RANGE`, `4 = HW_FAULT`.

> **Superseded 2026-08-26 by the shipped firmware.** This section's instinct was right — the node must not compute a level — but the implementation kept `RS485_PROTOCOL.md` §4.2's **10-byte layout** rather than shrinking to 8. The node sends `level_percent = 255` always, and the hub scales millimetres against its own per-tank calibration (§4.3's conclusion, reached the same way for the same reason).
>
> Keeping the wider layout was deliberate, and two bytes is a cheap price:
> - The frame layout stays fixed, so nodes and hub of different vintages stay mutually parseable — a value other than `255` in that byte identifies old firmware instead of silently shifting every subsequent field.
> - The `reserved` byte survives, and it is where the sensor-type flag goes if a tank ever moves to a 4-20 mA pressure transducer (§7.1). Shrinking the payload would delete the slot that migration path depends on.
>
> `sensor_status` as shipped uses `0 = OK`, `1 = BLIND_ZONE`, `2 = ECHO_TIMEOUT`, `3 = HW_FAULT` (no distinct `OUT_OF_RANGE` — a reading past the calibrated empty distance is a hub-side judgement now, not a node-side one).

**`CMD_READ_CLIMATE` response payload (6 bytes)** — unchanged from `RS485_PROTOCOL.md` §4.3.

### 3.5 ESP32 hub GPIO map — resolved

`docs/WIRING.md` §1 wins. It matches the hub that is physically built. `docs/HARDWARE.md` §3.1 is wrong and gets corrected, not reconciled.

| GPIO | Signal | Device | Notes |
| :--- | :--- | :--- | :--- |
| 16 | `RS485_RX` | XY-485 `RXD` | UART2 |
| 17 | `RS485_TX` | XY-485 `TXD` | UART2 |
| 21 | `I2C_SDA` | GY-SHT30-D | |
| 22 | `I2C_SCL` | GY-SHT30-D | |
| 32 | `IN_TWT_FLOT` | PC817 ch4 | `INPUT_PULLUP` |
| 26 | `IN_RL1_STAT` | PC817 ch1 | `INPUT_PULLUP` |
| 25 | `IN_RL2_STAT` | PC817 ch2 | `INPUT_PULLUP` |
| 33 | `IN_LPS` | PC817 ch3 | `INPUT_PULLUP`. **Reassigned 2026-08-27** — Aster `LPS`, `C`/`NO`. Tapped to demultiplex `AUX OP`, which reports that something faulted without saying what (`WIRING.md` §6.6) |
| 13 | `IN_ALARM` | Aster `AUX OP` relay, **direct** | `INPUT_PULLUP`, debounced 6-of-8. No optocoupler: the relay contact is already the isolation barrier, and the relay is enclosed, so the internal pull-up's ~73 µA is acceptable wetting. Moved off PC817 ch3 on 2026-08-27 — `WIRING.md` §6.6 |
| 5 | `US_TRIG_DOS` | AJ-SR04M (dosing) | Added 2026-08-25. Dosing node `0x01` deleted, sensor wired direct — `WIRING.md` §13 |
| 4 | `US_ECHO_DOS` | AJ-SR04M (dosing) | **1 kΩ/2 kΩ divider, 5V→3.3V.** Digital use only — `GPIO 4` is `ADC2` and ADC2 is dead while Wi-Fi is up |
| 34 | `IN_HPP_AC` | AC opto 1 | ADC1_CH6. **Corrected 2026-08-27:** module has its own 47 k pull-up to `VCC`; no external resistor — §3.5 |
| 35 | `IN_RWP_AC` | AC opto 2 | ADC1_CH7. Same onboard pull-up — §3.5 |
| 36 | `IN_HPP_CT` | SCT-013-030 clamp | ADC1_CH0, 11 dB. Added 2026-08-26 — §7.3 |
| 39 | `IN_RWP_CT` | SCT-013-030 clamp | ADC1_CH3, 11 dB. Added 2026-08-26 — §7.3 |
| 27 | `OUT_RLY_TWT` | Relay `IN1` | Active LOW. Phase C use |
| 23 | `OUT_RLY_RWT` | Relay `IN2` | Active LOW. Phase C use |
| 18 | `OUT_RLY_DOS` | Relay `IN3` | Active LOW. Phase C use |
| 19 | `OUT_RLY_AUX` | Relay `IN4` | Active LOW. Spare |
| 2 | `LED_STATUS` | Onboard LED | |
| 0 | `BTN_BOOT` | Onboard button | Config reset |

GPIO 34 and 35 are input-only pins with **no internal pull-up**. ~~The current sketch's `pinMode(pin, INPUT)` against an open-collector opto output leaves them floating. This is a defect on already-built hardware and must be fixed physically.~~

**Withdrawn 2026-08-27.** The fitted 240 V module is not a bare open-collector: it carries a **47 k pull-up from `OUT` to `VCC`**, silkscreened `47K VCC`, which is the reason it has a `VCC` terminal (`WIRING.md` §8). With `VCC` on 3V3, `pinMode(pin, INPUT)` is correct and there is nothing to retrofit. The floating reading that prompted this entry was traced to a **broken wire at the module**, since repaired. Both pins sit on ADC1, so `probeACInput()` in the hub sketch now measures them and separates idle-with-pull-up from genuinely floating — which a `digitalRead` cannot.

### 3.6 Node pin map (Nano 0x01-0x03, Pro Mini 0x04)

> **Amended 2026-08-25 (a):** node `0x04` is built on an Arduino Pro Mini (5V / 16 MHz), not a Nano. Same ATmega328P, same pin functions, same binary. The board differences are mechanical only (5V to `VCC` not `RAW`, `A4`/`A5` on inner pads, FTDI programming) and are specified in `WIRING.md` 10.1.
>
> **Amended 2026-08-25 (b):** node `0x01` (dosing) is **deleted**. The tank is ~1 m from the hub, so the sensor is wired direct to the ESP32 (`WIRING.md` §13). The fleet is three slaves: `0x02` and `0x03` ultrasonic Nanos, `0x04` climate Pro Mini. If either already-built node was jumpered as `0x01`, re-jumper it to `0x02` or `0x03`. The dashboard contract is unchanged — `tanks.dosing` keeps its shape and is sourced locally instead of over the bus; `nodes[]` drops to three entries.

| Pin | Signal | Nodes |
| :--- | :--- | :--- |
| D2 | `RS485_RX` | All (SoftwareSerial) |
| D3 | `RS485_TX` | All (SoftwareSerial) |
| D7 | `US_TRIG` | 0x01, 0x02, 0x03 |
| D8 | `US_ECHO` | 0x01, 0x02, 0x03 |
| A4 | `I2C_SDA` | 0x04 only |
| A5 | `I2C_SCL` | 0x04 only |
| D9 | `OUT_FAN_RLY` | 0x04 only |
| A0 | `ADDR_SEL0` | All |
| A1 | `ADDR_SEL1` | All |
| D13 | `LED_STATUS` | All |

### 3.7 Node addressing — RESOLVED 2026-08-25

`nano_node_test.ino` and `docs/WIRING.md` published **contradictory jumper truth tables** (`0x01`/`0x02` swapped, both-grounded mislabelled `0x03`, `0x04` missing).

**Resolved by writing the table from the observed hardware — no rewiring.** The three built boards presented three *distinct* jumper codes, so there was never an ambiguity to resolve with a soldering iron, only a lookup table to author. `common/protocol.h` carries it and `WIRING.md` §9.1 publishes it:

```c
static const uint8_t ADDR_MAP[4] = {  // raw = (A1 << 1) | A0, open = 1, GND = 0
  0x00,   // 0b00  both GND   -> unassigned, must not transmit
  0x02,   // 0b01  A1 to GND  -> RWT        (Nano #2, as built)
  0x03,   // 0b10  A0 to GND  -> TWT        (Nano #1, as built)
  0x04,   // 0b11  both open  -> Battery Rm (Pro Mini, as built)
};
```

Consequences recorded in `WIRING.md` §9.2: the arithmetic `return raw` decoder in `nano_node_test.ino:39-44` is superseded; the unjumpered default becomes `0x04`, so **a new board must be jumpered before it joins the bus**; both-grounded is now an explicit "do not transmit" code, usable to bench a spare while it sits on the bus. Confirm each node by boot print before bussing.

Address space stays at 2 jumper bits / 4 addresses (`0x01`–`0x04`). A third bit for future expansion is **deliberately skipped** — see §8.

---

## 4. Section 2 — Node firmware

One binary for all three nodes. The address jumper selects both the node ID and the sensor personality (`0x02`/`0x03` ultrasonic, `0x04` climate + fan relay). `0x01` remains a legal jumper setting but is unassigned — see §3.6 amendment (b).

### 4.1 The deaf-window defect

> **Amended 2026-08-25:** the sensors are **AJ-SR04M**, not JSN-SR04T. Same Trig/Echo interface and the same 35 ms timeout, but the `R19` mode pad must be empty or the board runs in UART mode and `ECHO` never pulses, and the `TRIG` width (10 µs nominal) is a per-batch tuning knob. See `WIRING.md` §9.0.

`pulseIn(PIN_US_ECHO, HIGH, 35000UL)` blocks for up to 35 ms. `SoftwareSerial` cannot buffer during that block. A 4-byte poll at 9600 baud occupies ~4 ms. With measurement on a free-running 250 ms timer, roughly **15 % of polls are silently lost**.

**Fix:** measure **immediately after transmitting a response**, never on a timer. The blocking window then falls while the master is addressing a *different* node, and the node is guaranteed listening whenever its own turn comes round.

**Cost:** the value returned is one poll cycle (~1 s) old. For water tanks this is immaterial and is documented as expected behaviour.

**Fallback:** if no poll is received for 10 s, resume free-running measurement at 1 Hz so the filter stays warm and the node remains independently useful (`plan.txt` §11).

Rejected alternative: moving RS485 to the Nano hardware UART (D0/D1). It works, but costs USB debugging on nodes that will live on a roof and in a battery room.

### 4.2 Filtering

- **Median of 5 samples**, taken back-to-back.
- **Range gate** against `min_valid_mm` (blind zone, ~250 mm) and `max_valid_mm`. Out-of-range samples are discarded before the median, not fed into it. A reading of 0 mm is `ECHO_TIMEOUT`, never a valid "full tank" — `plan.txt` §15.
- `signal_quality` derived from the spread of the 5 samples.

**Deliberately skipped:** the EMA smoothing and `MAX_LEVEL_CHANGE_PER_UPDATE` rate limiter from `plan.txt` §12. A median already suppresses the failure that actually occurs (a single spurious echo), and a rate limiter would mask a genuine rapid fill. An `EMA_ALPHA` config knob is left in place defaulting to disabled, so it can be switched on if a particular tank surface proves choppy.

### 4.3 Nodes report distance, not percentage

Nodes transmit **raw `distance_mm` plus status**. All tank geometry lives on the hub.

Rationale: recalibrating a rooftop tank becomes editing a web form rather than carrying a ladder and a laptop to the roof and reflashing a Nano. It also puts every calibration constant in one place, as required by `plan.txt` §25.

This is a deliberate departure from `RS485_PROTOCOL.md` §4.2.

### 4.4 Bus turnaround

The XY-485 is auto-direction, so there is no DE/RE pin to manage. The module still holds its driver enabled briefly after the last transmitted character. Slaves observe a **5 ms guard delay** before replying.

---

## 5. Section 3 — Hub firmware

### 5.1 Scheduling

Cooperative `millis()` scheduler. No explicit FreeRTOS tasks — four periodic jobs do not justify them.

| Job | Period |
| :--- | :--- |
| RS485 poll cycle | 1000 ms |
| Opto input sampling | 50 ms |
| SHT30 read | 5000 ms |
| WiFi supervision | 10 000 ms |
| `WebServer::handleClient()` | every loop |

`esp_task_wdt` is fed from `loop()`. No `delay()` anywhere in the operational path (`plan.txt` §16).

### 5.2 RS485 master

Non-blocking `SEND → WAIT → PARSE | TIMEOUT` state machine, one node per tick, strictly sequential — no two slaves may transmit at once (`plan.txt` §24).

- Response timeout **100 ms**, up to **3 attempts** per node per cycle.
- The cycle runs nodes back-to-back and then waits until 1000 ms since cycle start. If a cycle overruns (four dead nodes ≈ 1.2 s), the next begins immediately. Cycle time is a floor, not a guarantee.

**Node liveness is time-based, not counter-based:**

| State | Condition |
| :--- | :--- |
| `ONLINE` | Good reading within 3 s |
| `STALE` | Last good reading 3–10 s ago |
| `OFFLINE` | No good reading for > 10 s |
| `SENSOR_ERROR` | Responding, but `sensor_status` is not OK |

`OFFLINE` is never rendered as 0 % (`plan.txt` §15).

### 5.3 Framer

Byte-at-a-time sync on `0xAA 0x55`. The current `available() >= 7` followed by seven blind reads desynchronises permanently on a single stray byte. Resynchronising costs one frame instead of wedging the cycle.

### 5.4 AC input sampling

A 240 V / 50 Hz signal through an opto is a ~100 Hz pulse train; the output is LOW for only part of each 10 ms half-cycle.

The current `readACInputFiltered` samples 10 × 500 µs = **5 ms** and requires 8 of 10 LOW. It will report OFF while the pump is running.

**Fix:** sample across a **25 ms window** (more than one full mains cycle) and latch ON if *any* sample is active.

**Closed 2026-08-27 — fix not needed, premise was wrong.** Both AC channels were validated against live contactors and `readACInputFiltered` reports correctly with its existing 5 ms / 8-of-10 window. So `OUT` is not the 100 Hz pulse train this section assumed: the fitted module rectifies (MB6S bridge), clamps (5.1 V zener) and **smooths (100 µF)** ahead of the opto LED, holding the output steady for as long as mains is present. The 25 ms window is therefore unnecessary and `readACInputFiltered` stays as written.

The mechanism is inferred from the board and from the filter working, not from a scope trace. If a future batch of modules omits the 100 µF, `probeACInput()` names the failure directly — a full-rail swing instead of a steady low — and this section is the fix to apply.

### 5.5 Web server and concurrency

Plain synchronous `WebServer`, not `ESPAsyncWebServer`. Handlers execute inside `loop()`, so they cannot race the poll cycle for `SystemState`. This eliminates the entire concurrency class at zero cost.

**Deliberately skipped:** SSE and WebSockets from `plan.txt` §18. `dashboard.html` already polls at 1 s, which is ample for water.

Endpoints:

| Endpoint | Purpose |
| :--- | :--- |
| `GET /api/telemetry` | Complete `SystemState` as JSON |
| `GET /api/health` | Uptime, RSSI, reset reason, firmware version |
| `GET /api/config` | Current configuration |
| `POST /api/config` | Update tank geometry, thresholds, WiFi |

`/api/status`, `/api/tanks`, `/api/environment`, `/api/inputs` from `plan.txt` §18 collapse into `/api/telemetry`. Split them when a consumer needs a partial fetch.

### 5.6 Tank geometry and configuration

Per-tank, hub-side, stored in NVS via `Preferences`:

```
tank_id, tank_name
empty_distance_mm     // sensor reading with the tank empty
full_distance_mm      // sensor reading with the tank full
min_valid_mm          // blind zone
max_valid_mm
```

```
level_percent = clamp(100 * (empty_distance_mm - distance_mm)
                          / (empty_distance_mm - full_distance_mm), 0, 100)
```

`empty_distance_mm` and `full_distance_mm` are directly measurable with a tape and absorb sensor mounting offset, so no separate offset term is needed.

### 5.7 Logging

Structured single-line levels per `plan.txt` §26. State *transitions* are logged; steady state is not.

---
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

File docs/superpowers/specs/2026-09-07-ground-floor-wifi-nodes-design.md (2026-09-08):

# Ground-floor Wi-Fi nodes — design

**Date:** 2026-09-07
**Status:** approved, awaiting implementation plan
**Supersedes:** `RS485_PROTOCOL.md` §5 (nodes push to the hub). Nodes are now polled.

## 1. What this adds

Two ESP32 nodes on the ground floor, reached over the house LAN, polled by the
terrace hub, and shown on the dashboard and in RainMaker:

| Node | Where | Reads |
| :--- | :--- | :--- |
| `0x05` Sump | Sump manhole | AJ-SR04M ultrasonic, **or** a 4-20 mA submersible pressure transducer on the same `J-LOOP` / `J-PRESS` provision the tank nodes carry (`WIRING.md` §9.4) |
| `0x06` Utility | Motor starter panel | 3 × CT on the borewell (one per phase), 3 × CT channels on the sump motor (two clamps fitted now, third channel wired and read, clamp added later if needed), sump motor **PUMP ON** dry contact, RWT floaty, SHT30 temperature and humidity |

No pump control. No relay board. The 4-channel relay interlocks in
`WIRING.md` §11.2 are out of scope for this round and stay a Phase-2 option.

## 2. What the panels offer (from `images/groundfloor/`)

**Borewell** — Lauritz Knudsen MK1 direct-on-line starter with an NEC-49
three-phase level controller in series with the coil. The starter has no spare
auxiliary contact; the NEC-49 has no output. Its "Lower Sump Float" input
carries the sump float and its "Over Head Tank Float" input is shorted, so in
AUTO the borewell runs whenever the sump float allows. Both float loops are at
mains potential inside the NEC-49. **Nothing of ours touches this panel except
CT clamps on the motor tails 2/T1 4/T2 6/T3.**

**Sump motor** — Astero Submersible 2.0 HP controller. Terminal strip inside:
`PULSE O/P`, `TWT FLOTY (C, NC)`, `PUMP CONT. (C, NC)`, `RUNNING RELAY O/P (NO, C)`,
`STARTING RELAY O/P (NO, C)`, `PUMP ON (C, NO)`.

- `PUMP ON (C, NO)` is unused and is an isolated dry contact closed while the
  controller has the pump on. **This is the sump-motor run signal**, wired like
  the hub's `IN_ALARM`: two wires to a GPIO with a pull-up.
- `TWT FLOTY` is where the RWT float cable lands. Whether the node can read it
  depends on the voltage the Astero puts across the loop, **to be metered
  before any wire is connected**: low-voltage DC → an optocoupler across the
  loop; mains → not tapped, and `rwt_floty` reports `null`.
- `PUMP CONT.` has one wire to nowhere — an abandoned external-contactor
  option. Tape the loose end, leave the pair alone.
- Do not land anything on a pair that already has wires until the other end is
  known.

## 3. Topology

Hub pulls. A dedicated task on the hub (`gf_task`) polls each configured node
with `HTTP GET http://<ip>/api/telemetry`, 2 s timeout, and writes the result
into `hub_state_t` under the existing lock. It is its own task so a silent node
cannot stall the 2 s RS485 cycle.

| | |
| :--- | :--- |
| Poll period, node online | 5 s |
| Offline after | 3 consecutive misses (≈ 15 s) |
| Poll period, node offline | 30 s — keeps probing, cheaply |
| Back online | first good reply; cadence returns to 5 s |
| IP field empty | node "not fitted": no polling, no alert, cards hatched |

Drops and returns are logged as `EVT_NODE_OFF` / `EVT_NODE_ON` with the node
id, and feed the existing node-lost alert. Nodes are stateless and know nothing
about the hub.

## 4. Node JSON

Nodes report **raw readings only**. Every calibration constant lives on the hub
in NVS and is set from `/cal`, so reflashing a node never loses a number.

### 4.1 Sump `0x05`

```json
{"id":5,"fw":"a3cb57d","uptime_s":3840,"rssi":-64,
 "source":"ultrasonic","distance_mm":1750,"quality":95,"status":"OK",
 "loop_ua":null}
```

```json
{"id":5,"fw":"a3cb57d","uptime_s":3840,"rssi":-64,
 "source":"pressure","distance_mm":null,"quality":null,"status":"OK",
 "loop_ua":11200}
```

- `source` follows the `J-PRESS` shunt: fitted = `pressure`, off =
  `ultrasonic`. Read once at boot, like `ro_node.ino`.
- `status` ∈ `OK | BLIND | NO_ECHO | HW_FAULT`, the same `sensor_status_t` the
  RS485 tank nodes use. On the pressure source `HW_FAULT` means the loop is
  outside 3.5–21 mA: open, unpowered, shorted or miswired (§9.4.4 of
  `WIRING.md`).
- `loop_ua` is the raw loop current. The **hub** converts it, so the
  transducer's range is a `/cal` number and not a node build constant:
  `head_mm = (loop_ua − 4000) × range_mm / 16000`, then the same
  distance-alike convention as the tank nodes, `distance = range − head`,
  so the existing full/empty calibration applies unchanged (§9.4.1).
- Percent from a new `CAL_TANK_SUMP` entry: full mm, empty mm, and
  `press_range_mm` (0 = ultrasonic only).

### 4.2 Utility `0x06`

```json
{"id":6,"fw":"a3cb57d","uptime_s":3840,"rssi":-68,
 "bore_mv":[412,405,398],
 "sump_mv":[398,0,0],"sump_on":false,
 "rwt_floty":null,
 "t_deci_c":312,"rh_deci_pct":548,"sht_ok":true}
```

- `bore_mv` / `sump_mv`: per-channel AC RMS millivolts as the node measured
  them, order = clamp order on the node header. Three channels each. A channel
  with no clamp plugged in sits at the bias pedestal and reads a few mV of
  noise; the hub treats anything under `CT_NOISE_FLOOR_MV` as "no clamp" and
  reports that phase as `null`, never as 0 A — the same rule the hub applies
  to its own two channels.

  > **Correction, 2026-09-07 (annotation — the paragraph above is left as
  > written).** "sits at the bias pedestal" is wrong, and `WIRING.md` §11.3
  > copied it. The bias rail reaches an ADC pin only *through the plugged
  > clamp's winding* (bias → socket ring → coil → tip → 1 k → pin), so an
  > **empty socket reads ~0 V at the pin**, not the pedestal. Measured on the
  > hub's identical topology and recorded in `WIRING.md` §14.2 step 2, where
  > it cost an hour on 2026-09-06. The conclusion the paragraph draws is
  > unaffected — below `CT_NOISE_FLOOR_MV` still means "no clamp" and still
  > reports `null`, never 0 A — only the reason given for it. The pedestal
  > check that *does* matter is on a channel that is plugged in: a floating
  > pin swings on mains coupling and RMSes like a running motor, which is why
  > `sensors_util.c`'s `rms_mv()` reports 0 mV rather than a number.

- `sump_on`: the `PUMP ON` contact.
- `rwt_floty`: `true` closed, `false` open, `null` not wired.
- SHT30 at I²C `0x44`, the part the hub and battery node already use.
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

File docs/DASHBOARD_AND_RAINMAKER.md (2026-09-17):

# Local Web Dashboard & ESP RainMaker Integration Guide

**Document Version:** 1.0  
**Date:** 2026-08-24  
**Scope:** Local Network Web UI + AWS IoT-backed ESP RainMaker Cloud & Mobile Application

---

## 1. System Telemetry & Process Flow

The system telemetry directly visualizes the complete fluid balance and environmental status of the plant:

```
[Borewell Pump] ──> [Ground Sump (3.5m)] ──(Sump Motor)──> [RWT (Roof)] ──> [RO Plant Skid: RWP + Dosing + HPP] ──> [TWT (Roof)]
                                                                               │
                                                                               └── [Battery Room: SHT30 + Exhaust Fan]
```

---

## 2. Local Web Dashboard (Local Network Access)

The ESP32 Central Hub hosts a zero-dependency, ultra-responsive HTML5/CSS/JavaScript web server accessible by any PC, tablet, or smartphone connected to the local Wi-Fi router.
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

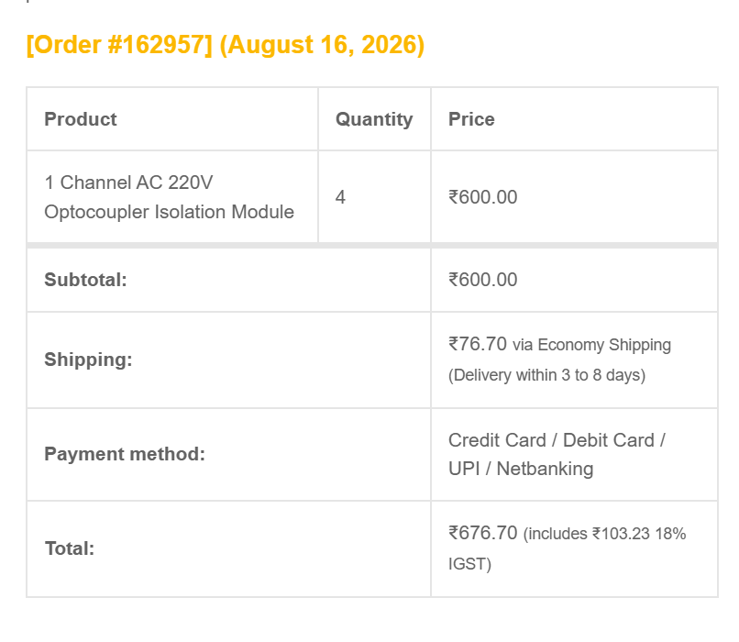
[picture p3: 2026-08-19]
images/hardware/hardware2.png

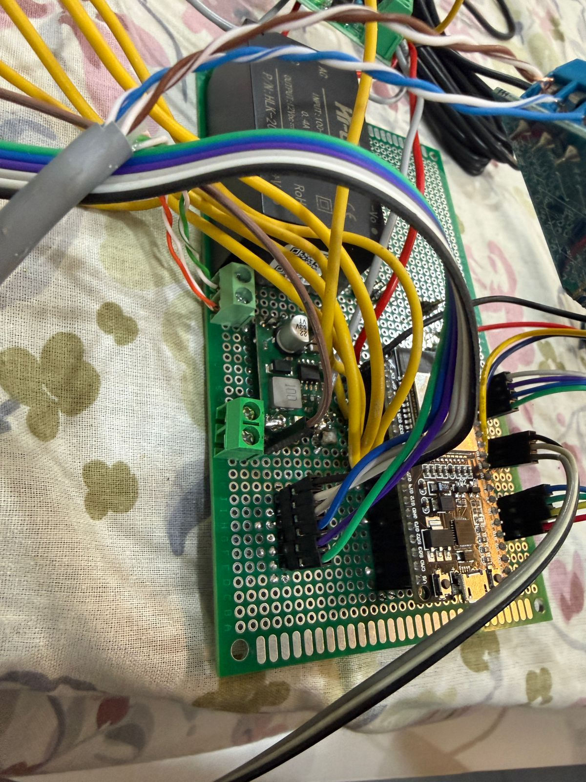
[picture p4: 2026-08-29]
images/hardware/hub_board_asbuilt_buck_headers.jpg

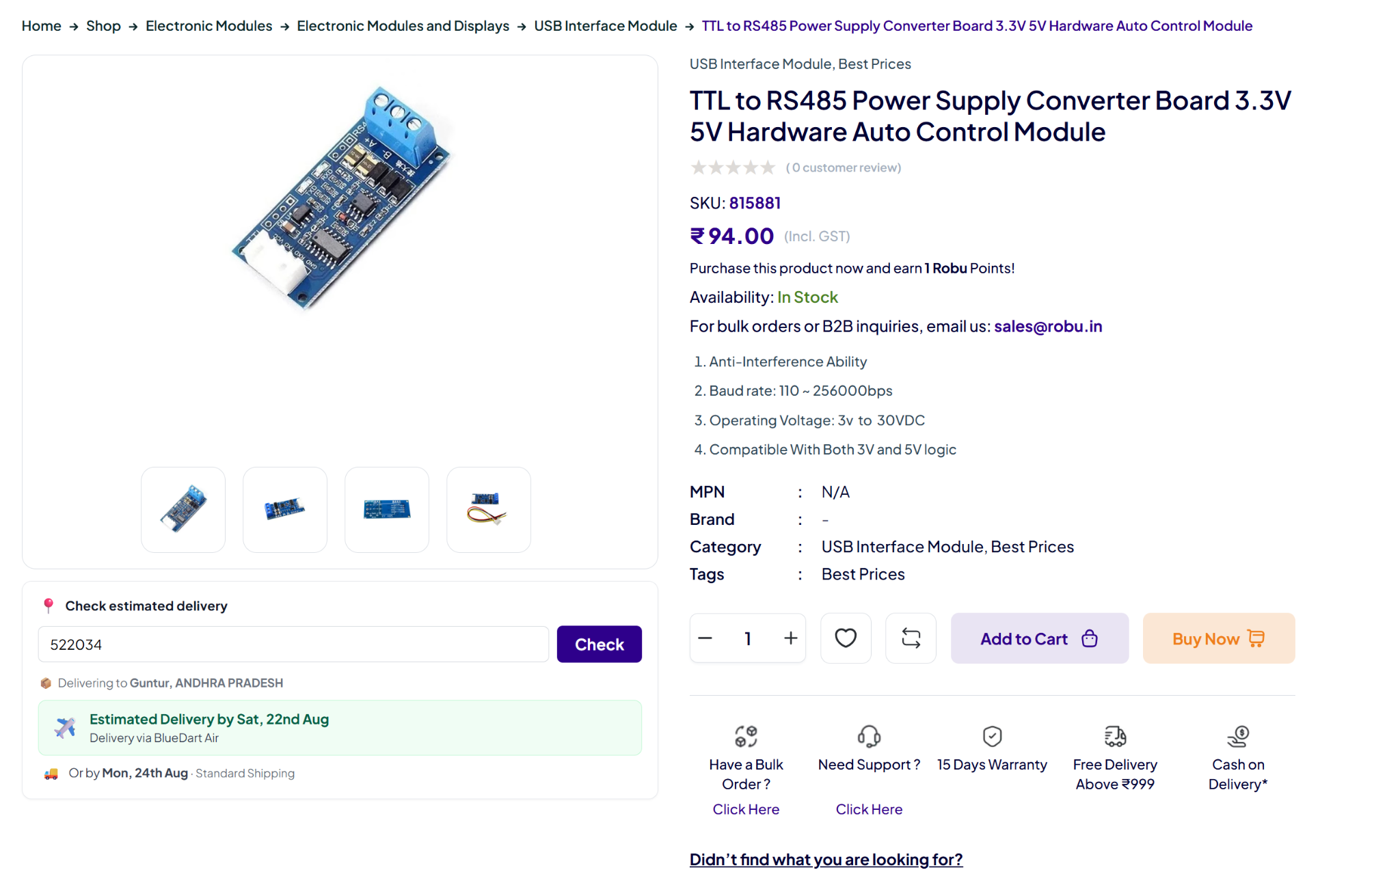
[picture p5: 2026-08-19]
images/hardware/RS485-transcever.png

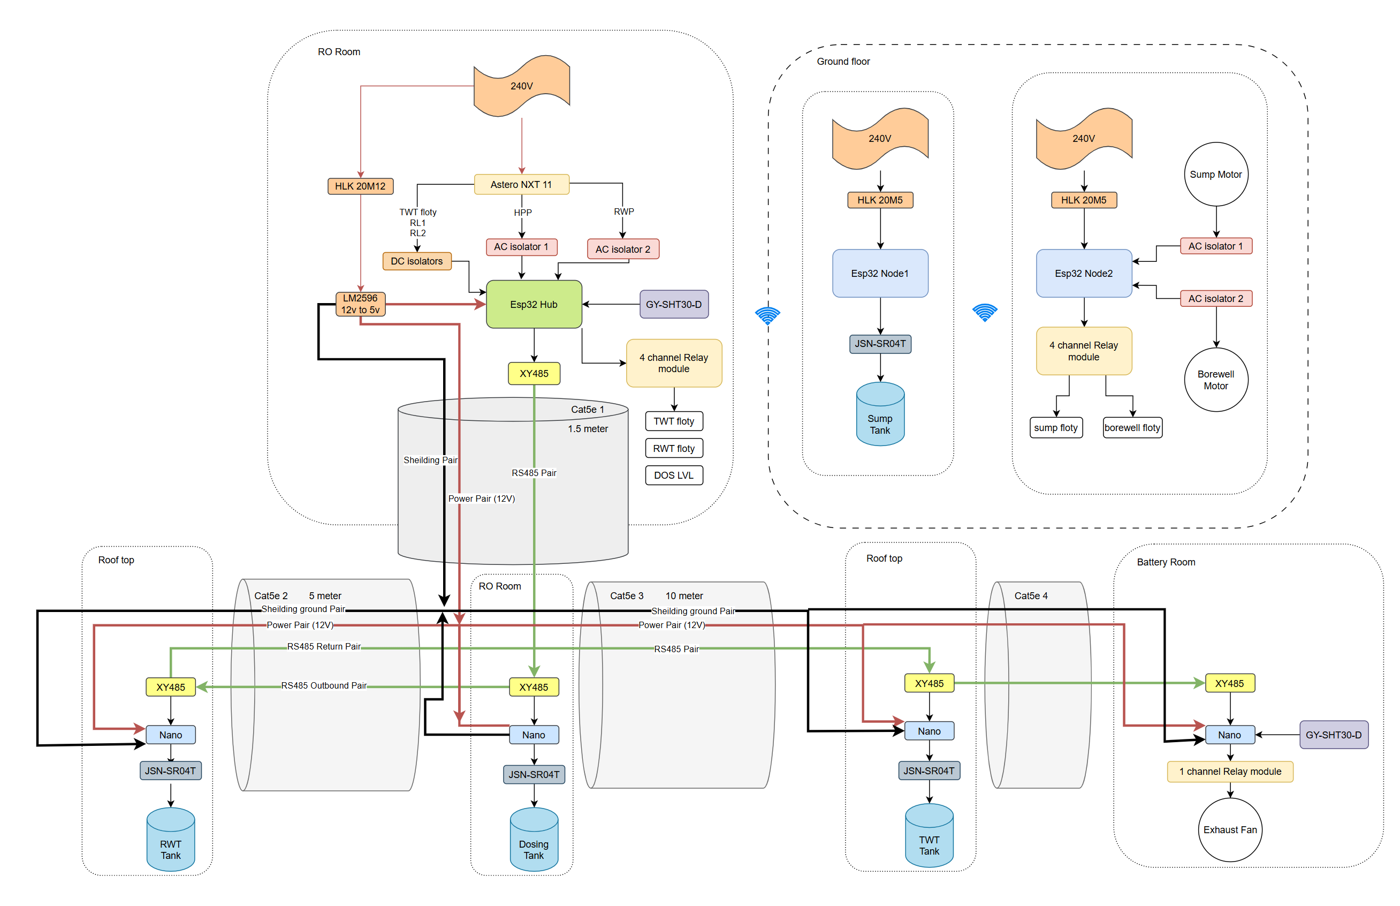
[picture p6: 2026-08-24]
images/architecture.png

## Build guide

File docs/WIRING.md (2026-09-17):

# Wiring & Interconnection Specifications

**Document Version:** 2.5  
**Date:** 2026-08-27  
**Scope:** Complete Pinout Mappings, CAT5e Drop Schedules, RS485 Daisy-Chain, 240V AC Isolation, 4-Channel Opto-Isolation (Inputs), Aster Terminal Contact Polarity & Alarm Output, 4-Channel Relay Module (Future Asterro Float/Level Emulation), I2C Environmental Sensor, and Tank Node Power & Wiring.

> **Pin allocation authority:** Section 1 below describes the hub **as physically built** and is the single source of truth, per `superpowers/specs/2026-08-25-ro-monitor-phase-b-design.md` §3.5. `HARDWARE.md` Section 3.1 is kept identical to it and is corrected — not reconciled — whenever the two diverge.

---

## 0. Build State — What Is Verified, What Is Still To Do

Kept at the top because it is the first thing anyone opening this document in the
RO room needs. **Last updated 2026-08-30.**

> **The hub as it is actually wired is drawn in
> [`images/hardware/wiring-Hub.jpg`](../images/hardware/wiring-Hub.jpg)** —
> every module, every header, every wire colour, drawn from the built board.
> Editable source: the **`Hub`** page of `wiring.drawio` at the repo root — the
> filename is drawio's own export name, so re-exporting overwrites it in place.
>
> **It draws the plant DEPLOYED, not the plant as it stands.** Every field
> connection to the Aster is on it: `LPS` to PC817 `IN3`, `ALARM` to `G13`, and all
> four relay outputs to the float terminals. **That was true when written and is no longer** — Relay 1 is landed on `TWT FLOTY` (§7.2, as-built 2026-09-13) and the other three are unsurveyed —
> §0.2 and §6.6 are the authority on what is actually connected, and §0.3.2 lists
> what the log looks like while they are not. A picture beats a checklist for
> anyone in a hurry, so read the two together or you will diagnose a fault in a
> wire that was never run.
>
> **And the board itself, photographed 2026-08-30:**
>
> | Photo | What it shows |
> | :--- | :--- |
> | [`hub_board_asbuilt_overview.jpg`](../images/hardware/hub_board_asbuilt_overview.jpg) | The whole perfboard. DevKit, HLK-20M12, RS485 module, the module headers along the right edge, and the mains-side opto boards on flying leads rather than on the board |
> | [`hub_board_asbuilt_psu_rs485.jpg`](../images/hardware/hub_board_asbuilt_psu_rs485.jpg) | HLK-20M12 markings legible (`100-240VAC 0.4A` → `12VDC 1.6A 20W`), the RS485 module's `A+`/`B-` screw terminal and its 4-pin `GND`/`RXD`/`TXD`/`VCC` JST, and the Cat5e landing |
> | [`hub_board_asbuilt_buck_headers.jpg`](../images/hardware/hub_board_asbuilt_buck_headers.jpg) | The 12 V → 5 V buck, both 2-pin distribution terminals, and **the female header strips the DevKit is seated in** |
>
> Start with these when diagnosing: this document explains *why* each connection
> is what it is, the drawing shows *where* it goes, the photos show *what is
> actually there*. **If any two disagree, meter the board** — no drawing,
> photograph or paragraph outranks a continuity test — which is exactly how the
> CT header's pin order was settled on 2026-08-30 (§0.2).

"Verified" below means *observed working on the hardware*, not *designed* and not
*compiled* — the distinction that let `IN_ALARM` sit in three documents and no
firmware for a day (§6.6, `docs/check_pinmap.py`).

### 0.1. Hub `0x00` — verified on the bench, 2026-08-27

| Subsystem | How it was verified |
| :--- | :--- |
| RS485 bus, nodes `0x02` / `0x03` / `0x04` | All three answering every poll cycle |
| Hub SHT30 (RO room) | Live temperature and humidity |
| Dosing ultrasonic (`GPIO 5` / `4`) | Echoing after a wiring fix |
| PC817 ch1-ch4 (`GPIO 26` / `25` / `33` / `32`) | **5 V injected into each input in turn**, each reporting under the right label — which is how the one-place channel rotation in §5 was found |
| 240 V AC optos (`GPIO 34` / `35`) | Validated against live contactors; the earlier "floating" reading was a broken wire at the module, since repaired |
| Hub relays ×4 (`GPIO 27` / `23` / `18` / `19`) | Cycled in sequence |
| Battery-room fan relay (node `0x04`, `D9`) | Clicks on command over RS485 |

### 0.2. Hub board — still to solder

**Corrected 2026-08-28:** nothing is connected to the Aster yet, and the tank
sensors are loose on the bench. The board-side headers are fitted; the field wiring
happens at deployment.

- [ ] **At deployment: connect PC817 `IN3` to the Aster `LPS` `C`/`NO` pair.** Nothing to *move* — `IN3` has never been wired. The output side (`V3` → `GPIO 33`) is already done. §6.6
- [x] **`IN_ALARM` header fitted 2026-08-27** — 2-pin: hub `GND` and `GPIO 13`, to the Aster `AUX OP` `C`/`NO` pair. No optocoupler, no resistor, no module. §6.6
- [x] **CT header fitted 2026-08-27, pin order confirmed with a meter 2026-08-30** — 4-pin, **`3V3` / `SN` / `SP` / `GND`**, not the 5-pin order in §14.0. This document had it as `3V3`/`SP`/`SN`/`GND` until the as-built diagram disagreed and the continuity test settled it; the DevKit's own header runs `3V3 | EN | SN | SP | G34`, so straight-across wiring gives `SN` first. **The breakout must therefore land RWP on pin 2 (`SN` = `GPIO 39`) and HPP on pin 3 (`SP` = `GPIO 36`)** — the reverse of what the old order implied. Leave both otherwise unconnected until the breakout exists.
- [ ] **Reseat or resolder the 4-ch relay header before deployment — one pin is intermittent.** 2026-09-02: the AUX relay (`GPIO 19`, `IN4`) would not click from `/cal`, then started working on its own. The firmware drove the pin and logged it correctly throughout, so this is downstream of the ESP32 and almost certainly a loose header pin.
  **It matters more than the spare relay suggests.** `IN4` carries nothing today, so its silence cost nothing — but `IN1`–`IN3` are on the same header, the same loom and the same handling, and they are TWT float, RWT float and dosing level. An intermittent on `IN1` tells the Aster the treated tank is full: production stops, then resumes, with nothing in any log to explain it.
  **The hub cannot detect this.** These are outputs with no feedback path, so no amount of firmware will ever see it. Physical fix only.
  **Acceptance check:** press all five buttons on `/cal` several times each while flexing the loom. Every press must click. Anything that skips once is not fixed.
- [ ] **Mark pin 1 on every header and mating plug on the hub board.** Not just the new ones: any header with a supply at one end and `GND` at the other shorts the rail if reversed, and most of them are built that way (§1). One pass with paint, once.

**Then verify, before trusting any of it:**

- [ ] Touch the two `IN_ALARM` wires together → alarm latches within one poll, the RO room flashes on the dashboard, a notification arrives
- [ ] Short PC817 `IN3` to `G` → `LPS` reads *Low pressure*; with the alarm also active the alert should name low feed pressure rather than saying "check the panel". Works on the bench with nothing attached to the Aster
- [ ] Confirm there are **no 120 Ω terminators anywhere on the RS485 bus**, and that the `R0` jumper on every XY-485 module is open. This bus has no bias network, so a single terminator takes every node offline — §12.3

### 0.3. Off-board, in order of what blocks what

- [ ] **CT breakout board** — two resistors and two capacitors once, then 1 kΩ + 100 nF + socket per channel. §14.1. Provable with no clamp attached: the pedestal should read ~1650 mV (§14.0)
- [ ] **2 × SCT-013-030** for HPP and RWP. Measure which socket pads the clamp actually reaches — meter it, do not read the silkscreen (§14.2)
- [ ] **6 × SCT-013-030** for the ground floor: three phases each on the sump and borewell motors (§11.3). Neither motor has a readable nameplate, so size from the starter's overload dial and a clamp meter (§11.3.1)
- [ ] **Tank calibration ×4** — RWT, TWT, dosing, and sump when it exists. Until a tank is calibrated its level reads `--`, never a plausible wrong number
- [ ] **Tank node headers `J-LOOP` + `J-PRESS`** — on both `0x02` and `0x03`, plus the 100 R / 1 k / 100 nF. Solder them while the boards are open, sensor or no sensor; the firmware ships the loop reader already. §9.4.2
- [ ] **Node `0x05` and `0x06`** — firmware built and OTA-capable (`firmware/gf_node`), polled from `/cal` by IP (§11, §11.4). Deployment is landing the CT clamps, `PUMP ON` and (after metering) `RWT FLOTY` on the physical panels — not writing any code.

### 0.3.1. Programming the hub

**As-built 2026-09-07: the DevKit was replaced and the onboard USB works again.**
The original module's CP2102 USB-serial chip was destroyed on 2026-08-28 by reverse
polarity on the `5V` pin; the ESP32 core survived and the board ran for ten days on
the FTDI path below. The replacement pulled straight into the socketed female
headers, so plain `idf.py -p COMx flash monitor` over the module's own USB is the
normal route now. **TODO: record the new module's USB chip (`VID_10C4` CP210x or
`VID_1A86` CH340) and COM port here once it has enumerated.**

The replacement is a blank chip: no Wi-Fi credentials, no RainMaker claim, no tank
calibration, no calibration password, no run-time ledger. It is a **new node** to
RainMaker — assisted claiming issues a fresh certificate, so delete the old hub
from the app and pair again (`DASHBOARD_AND_RAINMAKER.md`), then redo `/cal` end to
end. Check the new module's `SP`/`SN` labels against §1 before wiring the CT header;
DevKit variants differ in what they print there.

**Fallback — external FTDI on `TX0` / `RX0`.** Kept because it is the only path if
the USB chip is ever lost again, and because `PCB_HUB_MOTHERBOARD.md` `J_PROG`
exists for the same reason:

| | |
| :--- | :--- |
| Adapter | FTDI `FT232R`, `VID_0403/PID_6001` — the same one used for the Pro Mini nodes (§10.1) |
| Wiring | FTDI `TX` → ESP32 `RX0`, FTDI `RX` → ESP32 `TX0`, `GND` → `GND` |
| **Voltage jumper** | **3.3 V. NOT the 5 V used for the Pro Minis.** ESP32 pins are not 5 V tolerant; at 5 V the adapter's TX idles above `GPIO 3`'s rating |
| Auto-reset | `RTS` → `EN` **works** — esptool reports `Hard resetting via RTS pin` |
| Boot mode | **Manual, every flash.** `GPIO 0` is not driven by the adapter: hold `BOOT`, tap `EN`, release `BOOT`, then run esptool |

**Symptom if you forget the boot button:** `Failed to connect to ESP32: No serial
data received`. Identical wording to a wrong-port error, which is what makes it
confusing — the port is right, the chip is simply not listening.

With the FTDI path, `COM6` is the FTDI, and the module's own USB port must be left
unplugged so the two adapters do not fight over `TX0`.

**Keep the Arduino IDE closed while flashing.** Its Serial Monitor holds the port
and produces `PermissionError(13, 'Access is denied')`.

**The DevKit is socketed, not soldered** — it sits in female header strips
(`hub_board_asbuilt_buck_headers.jpg`), which is what made the 2026-09-07 swap a
pull-and-replace with no desoldering.

**Order by row pitch, not by pin count.** ESP32 DevKits are sold in more than one
row spacing — commonly 0.9" and 1.0", some 1.1" — and the listings almost never
say which, because the pin *count* and the pin *labels* can be identical across
pitches. A wrong-pitch board arrives looking correct and will not go into the
strips. **TODO: measure this socket and record pins-per-side and hole count here.**

**Measure it by counting holes, not with calipers.** The socket sits on 0.1"
perfboard, so the gap between the two female strips is a whole number of holes,
and that number *is* the spec to order against. Count it once and write it here.

Learned on 2026-09-03: a replacement bought on "38-pin ESP32 DevKit" alone had
matching pin count and matching labels, and a narrower row pitch. It could not be
seated. A module swap that should have taken a minute did not happen at all.

**The lesson worth carrying to the PCB:** one reversed supply took out the
programming interface of the board that runs the plant, and the board kept working
only because the ESP32 core survived. The replacement is just as unprotected —
mark pin 1 on the `5V` header before the buck is reconnected (§0.2). `PCB_HUB_MOTHERBOARD.md` §6 now specifies
reverse-polarity protection and a dedicated programming header for exactly this.

### 0.3.2. Reading the log while nothing is connected

On the bench, with sensors unmounted and no Aster wiring, these are the **expected**
readings — none of them is a fault, and each has been mistaken for one:

| Reading | Why |
| :--- | :--- |
| `RWT 171 mm q100 BLIND -> --` | A loose sensor pointing at whatever is 17 cm away. `q100` means the echo is *consistent*, which makes it look convincing |
| `DOS 0 mm NO_ECHO -> --` | Sensor unpowered or aimed at nothing. It reads normally when pointed across a room |
| `TWT 3861 mm OK -> 0%` | Measuring the room. Past `empty`, so 0% is arithmetically right |
| `LPS normal` | `IN3` is unconnected, so the PC817 output transistor is off and `GPIO 33` floats high. **Not** the Aster's `LPS` state |
| `ALARM clear` | `GPIO 13` unconnected, internal pull-up holds it high |
| `HPP/RWP idle, CT --` | No clamps, no breakout. `CT --` is the honest answer |
| `Dosing chemical low (0%)` alert | Follows from `DOS` having no echo. Real alert, meaningless input |

The rule this keeps proving: **a confident-looking number from an unconnected
sensor is the easiest thing in this system to misread as a fault.** Check what is
physically attached before diagnosing anything.

### 0.4. Known open, not blocking

- **An 8-channel PC817 board is owned and unused.** The 4-channel part was fitted
  because it was already to hand (confirmed 2026-08-27). So `RWT FLOTY` and
  `DOS LVL` cost no purchase — but they are **no longer channel-limited, they are
  pin-limited**. With `IN_ALARM` on `GPIO 13`, the only inputs left on this board
  are `12`, `14` and `15`, and 12 and 15 are strapping pins. Two more taps are
  possible; eight are not. **Do not swap the board just because the bigger one
  exists** — it would mean rewiring four working, injection-verified channels for
  no current need. The point of recording it is that the future decision is
  "rewire four channels", not "buy a board and rewire four channels".

- **Node `0x03` sample quality** sat at `q=60` on the bench. Leave `US_TRIG_WIDTH_US` at 10 until the sensor is over water; only widen to 20 if it stays low there (§9.0)
- **Production firmware has never run on hardware.** It compiles and the ported CRC and level maths are proven identical to the field-verified sketch, but BLE pairing and AP+STA coexistence are untested (`firmware/hub_prod/README.md`)

---

## 1. ESP32-S Central Master Hub Complete Pin Allocation

The ESP32-S serves as the Central Telemetry Hub. It gathers telemetry from the local SHT30 environmental sensor **and the directly-attached dosing tank ultrasonic sensor**, isolates and reads the Aster controller status lines via a 4-channel PC817 optoisolator (all 4 channels used: `RL1`, `RL2`, `LPS`, `TWT FLOTY` — `IN_ALARM` is a direct input, §6.6), controls a 4-channel relay module for future float/level emulation, and acts as the RS485 Modbus Master for three remote slaves.

### Master Pin Mapping Table

Drawn form of this same table, with the modules and wire colours:
[`images/hardware/wiring-Hub.jpg`](../images/hardware/wiring-Hub.jpg)
(`wiring.drawio`, page `Hub`).

| ESP32 Pin | Signal Label | Connected Device / Module | Module Pin | Direction | Electrical Characteristics & Notes |
| :--- | :--- | :--- | :--- | :---: | :--- |
| **3V3** | `+3.3V_LOGIC` | SHT30 Sensor, XY-485 Module | `VCC` | Power Out | Regulated 3.3V logic power bus (from ESP32 onboard LDO) |
| **GND** | `GND_LOGIC` | All Local Sub-Modules & Opto/Relay | `GND` | Power Out | Common DC logic ground |
| **VIN / 5V** | `+5V_RAW` | LM2596 / Mini560 12V -> 5V Buck | `VOUT+` | Power In | Regulated +5.0V DC main board power (from HLK-20M12 step-down) |
| **GPIO 16** | `RS485_RX` | XY-485 Auto-Flow RS485 Module | `RXD` | Input | UART2 Serial RX (3.3V TTL logic) |
| **GPIO 17** | `RS485_TX` | XY-485 Auto-Flow RS485 Module | `TXD` | Output | UART2 Serial TX (3.3V TTL logic) |
| **GPIO 21** | `I2C_SDA` | GY-SHT30-D Temp/Humidity Sensor | `SDA` | Bidirectional | I2C Data Line (4.7k pull-up to 3.3V) |
| **GPIO 22** | `I2C_SCL` | GY-SHT30-D Temp/Humidity Sensor | `SCL` | Output | I2C Clock Line (Standard 100 kHz / Fast 400 kHz) |
| **GPIO 32** | `IN_TWT_FLOT`| 4-Ch PC817 Opto Board (Channel 4) | `V4` | Input | Active LOW when Aster `TWT FLOTY` loop is closed (`INPUT_PULLUP`) |
| **GPIO 26** | `IN_RL1_STAT`| 4-Ch PC817 Opto Board (Channel 1) | `V1` | Input | Active LOW when Aster RL1 / Multiport valve contact is closed (`INPUT_PULLUP`) |
| **GPIO 25** | `IN_RL2_STAT`| 4-Ch PC817 Opto Board (Channel 2) | `V2` | Input | Active LOW when Aster RL2 / Multiport valve contact is closed (`INPUT_PULLUP`) |
| **GPIO 33** | `IN_LPS` | 4-Ch PC817 Opto Board (Channel 3) | `V3` | Input | Active LOW when the Aster `LPS` low-pressure contact (`C`/`NO`) is closed. **Took this channel from `IN_ALARM` on 2026-08-27** — §6.6 (`INPUT_PULLUP`) |
| **GPIO 13** | `IN_ALARM` | Aster `AUX OP` relay `C` / `NO` | **direct** | Input | Active LOW when the Aster `AUX OP` contact closes. **No optocoupler and no external parts** — two wires and `INPUT_PULLUP`, debounced in firmware. §6.6 |
| **GPIO 5**  | `US_TRIG_DOS`| AJ-SR04M (Dosing Tank) | `TRIG` | Output | 10 µs trigger pulse. Dosing sensor is wired direct to the hub — see Section 13 |
| **GPIO 4**  | `US_ECHO_DOS`| AJ-SR04M (Dosing Tank) | `ECHO` | Input | Echo pulse width. **5V → 3.3V divider required. As built: 1 kΩ series + 1.8 kΩ to GND → 3.21 V** (the design figure was 2 kΩ / 3.33 V). 1.8 kΩ is an E24 value that 2 kΩ is not, it sits *under* 3.3 V rather than over it, and the AJ-SR04M's 5 V `ECHO` still clears `V_IH` with room to spare. Do not "correct" the board to the 2 kΩ figure. |
| **GPIO 34** | `IN_HPP_AC` | 220V AC Opto Module #1 (HPP Contactor) | `OUT` | Input (GPI) | Active LOW when HPP contactor is energized. Module carries its own **47 k pull-up to `VCC`** (silkscreen `47K VCC`); wire `VCC` to 3V3 and no external resistor is needed — see §8 |
| **GPIO 35** | `IN_RWP_AC` | 220V AC Opto Module #2 (RWP Contactor) | `OUT` | Input (GPI) | Active LOW when RWP contactor is energized. Same onboard 47 k pull-up — see §8 |
| **GPIO 36** | `IN_HPP_CT`  | SCT-013-030 clamp, HPP `P` conductor | Tip (3.5 mm) | Input (GPI) | Analog. ADC1_CH0, 11 dB. Rides a shared 1.65 V bias rail — spec §7.3 |
| **GPIO 39** | `IN_RWP_CT`  | SCT-013-030 clamp, RWP `P` conductor | Tip (3.5 mm) | Input (GPI) | Analog. ADC1_CH3, 11 dB. Same bias rail — spec §7.3 |
| **GPIO 27** | `OUT_RLY_TWT`| 4-Ch 5V Relay Module (Relay 1) | `IN1` | Output | Active LOW: Emulates Treated Water Float Contact to Asterro (Phase C) |
| **GPIO 23** | `OUT_RLY_RWT`| 4-Ch 5V Relay Module (Relay 2) | `IN2` | Output | Active LOW: Emulates Raw Water Float Contact to Asterro (Phase C) |
| **GPIO 18** | `OUT_RLY_DOS`| 4-Ch 5V Relay Module (Relay 3) | `IN3` | Output | Active LOW: Emulates Dosing Level Contact to Asterro (Phase C) |
| **GPIO 19** | `OUT_RLY_AUX`| 4-Ch 5V Relay Module (Relay 4) | `IN4` | Output | Active LOW: Auxiliary / Interlock dry contact override (Phase C, spare) |
| **GPIO 2** | `LED_STATUS` | Onboard DevKit Blue LED | Anode | Output | System Heartbeat & Modbus polling activity indicator (No external wire needed) |
| **GPIO 0** | `BTN_BOOT` | Onboard DevKit BOOT Button | Switch | Input | Factory Reset / AP Provisioning Mode trigger (No external wire needed) |

**Pin selection constraints — re-check these before any reshuffle:**
* **GPIO 34-39 have no internal pull-up** — but the AC opto modules supply their own. **Corrected 2026-08-27:** the fitted module has a **47 k pull-up from `OUT` to `VCC`**, printed on the silkscreen as `47K VCC`, which is why it has a `VCC` terminal at all (§8). With `VCC` on 3V3 the pin idles high and `pinMode(pin, INPUT)` is correct. No external resistor is required, and the "outstanding hub defect" recorded in phase-B spec §3.5 was a misreading of this part. What *does* float the pin is `VCC` or `OUT` losing continuity — observed once on this build, from a broken wire at the module. 47 k is a weak pull-up, so a parallel 10 k remains available as noise-hardening on a long `OUT` run; that is a tuning choice, not a fix.
* PC817 outputs are open-collector too, so all four dry-contact channels sit on pins that support `INPUT_PULLUP`: GPIO 25/26/32/33.
* **Every header on this board can be plugged in backwards, and several of them short the rail when you do.** This is a board-wide property, not a quirk of one connector: wherever `3V3` or `5V` sits at one end of a header and `GND` at the other, reversal puts them onto each other. Some connectors only swap signals when reversed and are recoverable; the powered ones are not. **The convention is therefore one rule applied everywhere — mark pin 1 on every header and on every mating plug.** A dab of paint is enough, and it is worth more than any per-connector note, because the person who reverses a plug at 11 p.m. is not reading this document.
* **Silkscreen names that are not GPIO numbers, on the DevKit fitted here.** `SP` is `GPIO 36` and `SN` is `GPIO 39` (§14.0). More dangerously, this board breaks out **`SD2` `SD3` `CMD` `SD0` `SD1` `CLK`** along the bottom of both headers — those are **`GPIO 6-11`, the SPI flash**. They look like free pins and using one prevents the board from booting. There are no spare pins hiding there.
* **`GPIO 13` carries `IN_ALARM` directly, with no optocoupler** (§6.6). Of the four pins left free — 12, 13, 14, 15 — **12 and 15 are strapping pins** (12 selects flash voltage at boot), so 13 was taken and **14 is the last comfortable spare on this board**.
* GPIO 6-11 are wired to the SPI flash and unusable. GPIO 1/3 are the USB serial console. GPIO 12, 13, 14 and 15 remain free — 13 is the natural home for a fifth PC817 channel if one is ever added. **They are all ADC2 and therefore useless for analog while Wi-Fi is up**, which is why the two CT channels take `GPIO 36` and `GPIO 39` (ADC1) instead. Those were the last two free ADC1 pins on this hub.
* `GPIO 4` is `ADC2_CH0`. ADC2 is unusable while Wi-Fi is active, but this pin is used as a **digital** input, which is unaffected. Do not repurpose it for analog.
* `GPIO 5` emits a brief pulse at boot (strapping pin). On a `TRIG` line that costs one spurious ranging cycle at power-up and nothing else.
* GPIO 27/23/18/19 drive relay opto inputs only. They idle HIGH (relay de-energized) through reset and boot, which is the fail-safe state defined in Section 7.2.

---

## 2. Power Architecture & Voltage Distribution

```
 230V AC Mains (From Plant Contactor Panel)
      |
      v
 +----------------------------------------------------------+
 | HLK-20M12 Encapsulated Power Supply                      |
 | Input: 100 - 240V AC (50/60 Hz)                          |
 | Output: 12.0V DC (1.66A, 20W Isolated SELV)             |
 +----------------------------+-----------------------------+
                              |
                              +------------------------------> Main 12V DC CAT5e Trunk Line
                              |                                (Power to Remote Tank Nodes)
                              v
 +----------------------------------------------------------+
 | Central Skid DC-DC Buck Converter (LM2596 / Mini560)     |
 | Input: 12V DC                                            |
 | Output: 5.0V DC (2.0A max)                               |
 +----------------------------+-----------------------------+
                              |
                              +------------------------------> ESP32 5V / VIN Pin
                              +------------------------------> 4-Channel Relay Module JD-VCC (Coil Power)
                              |
                              v
 +----------------------------------------------------------+
 | ESP32 Onboard 3.3V LDO Regulator                         |
 +----------------------------+-----------------------------+
                              |
                              +------------------------------> SHT30 Temp/Humidity Sensor (VIN)
                              +------------------------------> Central XY-485 Module (VCC)
                              +------------------------------> 4-Channel Relay Module VCC (Opto 3.3V)
```

---

## 3. SHT30 Environmental Sensor Wiring (Central Hub)

```
  ESP32-S Hub (3.3V Logic)          GY-SHT30-D Module
 +------------------------+        +-------------------------+
 | 3V3 (3.3V Power Out)   +------->| VIN / VCC               |
 | GND                    +------->| GND                     |
 | GPIO 21 (I2C SDA)      +------->| SDA                     |
 | GPIO 22 (I2C SCL)      +------->| SCL                     |
 |                        |        | AD / ADDR (UNCONNECTED) | Default I2C Address: 0x44
 |                        |        | AL / ALERT (UNCONNECTED)| Alarm pin not required
 +------------------------+        +-------------------------+
```

---

## 4. Central Hub RS485 Transceiver (XY-485) Wiring

```
  ESP32-S Hub (3.3V Logic)          XY-485 Auto-Direction Module
 +------------------------+        +-------------------------+
 | 3V3 (3.3V Power Out)   +------->| VCC                     |
 | GND                    +------->| GND                     |
 | GPIO 16 (UART2 RX)     +------->| RXD                     |
 | GPIO 17 (UART2 TX)     +------->| TXD                     |
 +------------------------+        | A+  --> RS485 Bus (A+)  |
                                   | B-  --> RS485 Bus (B-)  |
                                   +-------------------------+
```

---

## 5. 4-Channel PC817 Optoisolator Module (Sensor Inputs)

Provides galvanic isolation for reading dry contacts and low-voltage status lines from the Asterro controller and Multiport Valve. The board fitted to the built hub is the **4-channel** part. It was wired `RL1`, `RL2`, `LPS`, `TWT FLOTY` — **and its input side is now disconnected from the Aster following the 2026-09-13 overflow (§5.3).** `TWT FLOTY` is never to be re-tapped; `RL1` and `RL2` are volt-free multiport-valve status outputs and may go back after §6.4 Step 2; `LPS` is an Aster input like `TWT FLOTY` and must be metered before any decision, because a shunt there masks the HPP dry-run protection. **`LPS` took channel 3 from `IN_ALARM` on 2026-08-27** — that signal needed no optocoupler and moved to a direct input (§6.6), which is what made room for `LPS` without an 8-channel board. Tapping `RWT FLOTY` or `DOS LVL` directly would require swapping in an 8-channel board — neither is needed for Phase B, since those tanks are measured by the RS485 ultrasonic nodes instead.

### 5.1. Module Architecture & Jumpers
* **Input Side (Left):** `IN1`..`IN4` (+) and `G` (Return) with onboard 3k ohm current-limiting resistors (compatible with 3.3V to 24V DC).
* **Output Side (Right):** `V1`..`V4` (Signal) and `G` (Ground). Open-collector phototransistors.
* **Jumpers:** Keep all black jumper caps installed (Default position).
* **ESP32 Connection:** ESP32 uses internal `INPUT_PULLUP`. No external `VCC` connection is required on the output side.

```
            INPUT SIDE (Left)                            OUTPUT SIDE (Right)
    +---------------------------------+          +---------------------------------+
    | [ IN1 ] (RL1 contact loop)      |          | [ V1 ] --> ESP32 GPIO 26        |
    | [ IN2 ] (RL2 contact loop)      |          | [ V2 ] --> ESP32 GPIO 25        |
    | [ IN3 ] (LPS loop, see 6.6)     |          | [ V3 ] --> ESP32 GPIO 33        |
    | [ IN4 ] (TWT FLOTY loop)        |          | [ V4 ] --> ESP32 GPIO 32        |
    | [  G  ] (Common input return)   |          | [  G ] --> ESP32 GND            |
    +---------------------------------+          +---------------------------------+
```

**As-built 2026-08-27, verified by injection.** The channel order above is a
one-place rotation of the order this document carried until now: `RL1` `RL2`
`ALARM` `TWT` rather than `TWT` `RL1` `RL2` `ALARM`. It was checked by injecting
5V into each input in turn and reading the hub's `[Opto Inputs]` line — all four
report under the right label, so the `V1..V4` runs match the table. Verify this
way after any rework, never by tracing the ribbon: a rotation still lights all
four channels, and the label it would cross `ALARM` with is `RL2`. A silently
mislabelled plant-fault flag is the one failure here that does not announce
itself.

### 5.2. Wetting Loop for Volt-Free Contacts

Every Aster contact tapped here is volt-free, so the loop must be wetted from our own 12V rail. Series the contact between +12V and the channel input. The board's onboard 3k resistor sets roughly 4 mA, which is above the HF3FF minimum wetting current and far below its rating.

```
  +12V DC (HLK-20M12 rail) --------> Aster terminal [ C      ]
                                     Aster terminal [ NO/NC  ] --------> PC817 [ INn ]
  12V GND ------------------------------------------------------------> PC817 [  G  ]

  Contact CLOSED -> ~4 mA through the opto LED -> phototransistor conducts -> GPIO reads LOW
  Contact OPEN   -> no current                 -> internal pull-up wins    -> GPIO reads HIGH
```

**Never apply this 12V wetting loop to a terminal the Aster panel energizes itself.** Confirm each tapped pair reads 0V AC and 0V DC across it, in both healthy and faulted states, before wiring. Procedure in Section 6.4.

### 5.3. Incident 2026-09-13 — this rule was broken on `TWT FLOTY`, and what it cost

**The treated water tank overflowed while the plant ran, and no interlock stopped it.** The plant had stopped correctly on tank-full for as long as it has existed. It stopped doing so after the hub's opto channels were landed on the Aster.

The rule that would have prevented it is the paragraph directly above, and it predates the fault. `TWT FLOTY` is exactly such a terminal: §6.1 is headed "**Input** Terminal Polarity" — the Aster wets and senses that loop itself and the float is only a switch inside it. The §6.4 Step 2 characterisation was run on the `ALARM` pair, where it belonged, and never on the float terminals.

**What was established, in order, and what each step ruled out:**

| Observation | Rules out |
| :--- | :--- |
| Plant stopped on tank-full for years before the hub was introduced | a controller setting, a configuration change, `MANUAL` mode |
| Display never showed `TW TANK FULL!!` while the tank overflowed | `MANUAL`, which would still show the state on the display |
| Float lifted by hand mid-run produced no stop; the same float state after a stop/start read full correctly | a stuck, fouled or mis-mounted float, and every mechanical cause |
| Identical behaviour with the hub powered **off** | the 12V drive by itself — see below |
| `RWT FLOTY`, `DOS LVL` and `HPS` also failed to stop a running plant | a fault confined to one channel |

**Powering the hub down does not take it out of the circuit.** With the hub unpowered, `[C]` is still tied to the 12V rail and `[NC]` still reaches the 12V return through the 3k resistor and the PC817 input LED. The two Aster terminals stay joined, through a diode and a dead supply. Only lifting the wires removes the hub, so "I switched the hub off and it still did it" is not the exoneration it looks like — it was read that way for most of an afternoon.

A diode is also a threshold device, which accounts for the one observation that seemed to contradict everything else. At Aster power-up that input is not yet driven hard, the LED stays below its forward voltage, the loop reads genuinely open, and the panel correctly reports `TW TANK FULL!!` and refuses to start. Once running and driving the input, the LED conducts and the same open float reads closed. One piece of wiring, two behaviours, decided by what the controller is doing at that instant.

> **Amended 2026-09-14 — the fault is INTERMITTENT, and that weakens several rows of the table above.** On the following day the plant stopped on tank-full correctly, with the same wiring still landed. Every row above rests on a single observation, and a single observation of an intermittent fault proves much less than it appears to. In particular "identical behaviour with the hub powered off" may have been an unlucky sample rather than proof of the phantom path, and the interlocks that "failed" may have failed on that attempt rather than always. Treat the table as the sequence of reasoning, not as four proven eliminations.
>
> **What intermittency points at.** Two candidates, and they are not exclusive:
>
> * **A marginal connection in the hub's own leg.** Two conductors under one screw - the float's and ours - is precisely the arrangement that makes and breaks. When our wire makes contact the shunt exists and the float loses authority; when it does not, the plant behaves correctly. Every trip to the terrace disturbs that block and re-rolls the dice, which also explains why the behaviour changed after a visit.
> * **The LED sitting at its conduction threshold.** A PC817's forward voltage moves about -2 mV/degC, and this hub is on a terrace. Hot afternoon, lower Vf, the LED conducts and masks the float; cool morning, it does not. The overflow happened during the day. The hub's own SHT30 and the dashboard history can test this - correlate the failures against RO room temperature and time of day.
>
> **Neither changes the remedy, and both raise its urgency.** An interlock that works when you test it and fails when you do not cannot be validated by watching it work. It can only be fixed by removing the cause. Nobody should read "it stopped correctly today" as evidence that the tap is safe.

**All four channels share one return, and that is why the blast radius is not one channel.** §5.1: `IN1`..`IN4` against a single `G`, and §5.2 wets every channel from the same +12V rail back to that same `G`. Terminal pairs the Aster treats as separate inputs end up commoned together through the hub. That is the most plausible reason `RWT FLOTY` and `DOS LVL` stopped acting as well, and it is why the remedy below is all four channels rather than the one that was found first.

**Standing instruction until every interlock has been re-verified on the plant:** the opto board input side is disconnected from the Aster entirely — `IN1`..`IN4`, the `G` return, and every +12V leg landed on a `[C]`. Nothing goes back onto any Aster terminal until §6.4 Step 2 has been run on that pair and it has read 0V AC and 0V DC in both states.

**`TWT FLOTY` is not to be re-tapped at all.** The treated water tank is measured by the ultrasonic on node `0x03`, and that is already what the dashboard and every alert use — `DASHBOARD_AND_RAINMAKER.md` records the deliberate decision that TWT-full comes from the level and not from the Aster float. The float bit was a nice-to-have. It cost a working safety stop.

---

## 6. Aster NXT Terminal Contact Polarity & Alarm Output

**Sources of truth:** `docs/ASTERO-NXTG-1_opt.pdf` (Aster NXT manual) — terminal list p.3, input/output configuration p.8-10, troubleshooting table p.12 — cross-checked against the board silkscreen photographed in `images/IMG_2836.JPG`.

> **Do not infer polarity from the `NO` / `NC` silkscreen alone.** Those marks name the contact form of the **field device at rest**, not the state the panel requires while running. On this controller `LPS` and `HPS` are both silkscreened `C NO` and behave in *opposite* directions.

### 6.1. Input Terminal Polarity (Verified)

| Terminal | Silkscreen | Field device | At rest (0 bar / normal tank) | **While running normally** | Open circuit is read as |
| :--- | :---: | :--- | :--- | :--- | :--- |
| `LPS` | `C` / `NO` | Low pressure switch, setpoint **below** normal feed pressure | open | **CLOSED** | `LOW PRESSURE!!` |
| `HPS` | `C` / `NO` | High pressure switch, setpoint **above** normal RO pressure | open | **OPEN** | normal — no fault |
| `TWT FLOTY` | `C` / `NC` | Treated water tank float | closed | **CLOSED** | `TW TANK FULL!!` |
| `RWT FLOTY` | `C` / `NC` | Raw water tank float | closed | **CLOSED** | `RW TANK EMPTY!!` |
| `DOS LVL` | `C` / `NC` | Dosing tank low-level float | closed | **CLOSED** | dosing low fault |

**Why `LPS` and `HPS` invert despite identical silkscreen.** Both are the same physical contact form — open at zero pressure, closing once pressure rises past their setpoint. What differs is where that setpoint sits relative to normal operating pressure:

```
  LPS setpoint  ~0.5-1 bar   ----+
                                 |   normal running feed pressure  (~2-3 bar)
                                 +--> LPS sits CLOSED while running
                                        opens only when feed fails      => closed = permissive

                                     normal running RO pressure      (~10-14 bar)
  HPS setpoint  ~18-20 bar   ----+
                                 +--> HPS sits OPEN while running
                                        closes only on over-pressure    => closed = trip
```

Manual p.12 confirms both directions: `LOW PRESSURE!!` lists *"LPS not connected"* as a cause, while the `HIGH PRESSURE!!` row does not — its wiring-error cause is *"check, is it C NO contact"*, i.e. a **closed** loop landed on `HPS` reads as over-pressure. The same page instructs *"Floaty is not connected. Short FLOATY terminal by an external wire link"*, confirming closed = healthy on the `NC`-form inputs.

### 6.2. As-Built Deviations Recorded on This Plant

| Observation | Date | Consequence |
| :--- | :--- | :--- |
| `HPS` terminal has **no field wiring** and the plant runs normally | 2026-08-25 | Consistent with 6.1 (open = healthy). Means there is **no controller-level over-pressure protection**, and **no `HPS` signal exists for the hub to monitor** — do not publish an `hps` state. Confirm on site whether `HI PRESS SW` is `ON` (enabled, watching a switch that can never close) or `OFF` (bypassed) and record the answer here. |
| `LPS` silkscreen is `C` / `NO` | 2026-08-25 | `RO_HARDWARE_ANALYSIS.md` previously recorded `C` / `NC`; corrected there. |
| **No interlock stopped a running plant** — `TWT FLOTY` by float, `RWT FLOTY`, `DOS LVL`, `HPS` | 2026-09-13 | Treated water tank overflowed. Root cause is the hub's opto wetting loops on the Aster's own input terminals, §5.3. `HPS` is a null result either way: it has no field wiring (row above). Every interlock must be re-verified physically, one at a time, before the plant runs unattended again. |
| The Aster **does** act on `TWT FLOTY` mid-run | 2026-09-13 | Established by the years of correct operation before the hub. An intermediate diagnosis that the input was "start-permissive only" was drawn from the broken system and is wrong — recorded here because it is the plausible-sounding conclusion somebody will reach again. |

### 6.3. The `ALARM` Terminal Is the Configurable AUX OP

Physically: a 2-screw pair on the upper-right block, immediately right of the third `HF3FF-012-1ZST` and left of `RSV` — the volt-free `C` / `NO` pair of that third relay (`images/IMG_2836.JPG`).

Logically it is the panel's **AUX OP**, and its meaning is a software setting, not a fixed function:

| `AUX OP` setting | Relay energizes when |
| :--- | :--- |
| `ALARM` | any fault is active (this is what our telemetry assumes) |
| `DOSING PUMP` | HPP is running |
| `PMP ON` | RWP is running |

Read the current value under **password 678** (Input Configuration, manual §1.4): press `<` and `>` together, enter `678`, scroll to `AUX OP:`.

> **Resolved 2026-08-26 — observed on the plant.** The pair sits **open in normal running and closes when there is an issue**, which stops the plant. That is `AUX OP` = `ALARM` behaving as this document assumed, on the `C` / `NO` pair, and it is the useful case: a genuine fault flag rather than a pump-run signal. The risk below was worth carrying and is now closed.
>
> *Original risk, kept for the reasoning:* `RL1` / `RL2` are documented here as multiport-valve status, which implies `MPV CNTRL` is `ON`, and the manual states *"IF ON, one has to configure AUX OP as PMPON when there is AMPV in pretreatment."* Had `AUX OP` been `PMP ON`, this terminal would be a pump run signal and every "controller trip" alert built on it would have been wrong.

**What this buys, and its one limitation.** `IN_ALARM` LOW means the controller has faulted — actionable on its own, no inference needed, and the most valuable single bit the Aster offers. What it does *not* carry is **which** fault: the panel multiplexes every condition onto one contact, so the ESP32 knows something tripped but not whether it was high pressure, a level interlock or a sensor. Alert text must therefore say *"controller fault — check the panel"* rather than naming a cause it cannot know.

> **Amended 2026-08-27 — partly solved.** `LPS` is now tapped on its own channel (§6.6), which demultiplexes the commonest cause. `IN_ALARM` closed *with* `IN_LPS` closed is low feed pressure and the alert names it; `IN_ALARM` closed with `IN_LPS` open still has to say "check the panel". So the limitation above holds for every other condition, and no longer for the one that trips most often.

Pairing it with the two AC optos does narrow things usefully: `IN_ALARM` closed while `IN_HPP_AC` reads stopped is a genuine trip, whereas the plant idling with `IN_ALARM` open is simply a satisfied TWT float and needs no alert at all.

### 6.4. Commissioning Procedure — Verify, Then Sense

**Step 1 — ~~confirm `AUX OP` = `ALARM`~~ (6.3). Done 2026-08-26:** observed open in normal running, closed on a plant issue. Proceed to step 2.

**Step 2 — trigger a fault and characterise the contact electrically.** The unwired `HPS` pair is the cheapest trigger: no wire is disturbed and no timer stands in the way.

```
  Short HPS [ C ] to [ NO ] for ~2 s
    -> display shows "HIGH PRESSURE!!", AUX OP relay energizes
    -> measure across the ALARM pair, both states:
         V~ and V= = 0 in both  -> volt-free dry contact  -> Step 3
         230 V~ when tripped    -> switched mains         -> Step 3 (AC opto variant)
         12 V= when tripped     -> switched 12 V          -> Step 3, omit external 12V rail
    -> power down, confirm with an ohmmeter: open idle, ~0 ohm tripped
  Remove the jumper -> fault clears.
```

If shorting `HPS` produces nothing, `HI PRESS SW` is `OFF` (bypassed); use `DOS LVL` (open one wire) instead. The HPP stopping during this test is a normal protective action — do not hold the short or cycle it repeatedly, the contactor pays for it.

**Step 3 — wire the sense channel.**

*Volt-free result (expected):* PC817 channel 3 per Section 5.2 — `+12V -> ALARM [C]`, `ALARM [NO] -> IN3`, `12V GND -> G`, `V3 -> GPIO 33`, `INPUT_PULLUP`, alarm = LOW. No new hardware: the board already fitted had a spare channel.

*Switched-mains result:* do **not** use the PC817. Add a 220V AC opto module wired as in Section 8 (`L` = switched leg, `N` = the other screw), `OUT` -> GPIO 33 (the module's own 47 k to `VCC` covers the pull-up, as on GPIO 34/35 — §8). Note this is a **fifth** AC opto module; the BOM's four are already allocated.

**Step 4 — debounce in firmware.** The contact bounces and the HPP contactor induces blips on the loop. Require a sustained state:

```c
// IN_ALARM on GPIO 13 (moved off PC817 ch3 2026-08-27, section 6.6),
// INPUT_PULLUP, active LOW. Latch after 200 ms sustained. The shipped
// firmware debounces 6-of-8 inside alarm_active() instead - same intent.
static uint32_t t_edge;
static bool raw, alarm;
bool now = !digitalRead(PIN_IN_ALARM);
if (now != raw)            { raw = now; t_edge = millis(); }
else if (millis() - t_edge > 200) { alarm = raw; }
```

### 6.5. Fault-to-Alarm Timing (Do Not Assume It Is Instant)

Configured delays sit between a physical fault and the AUX OP relay picking up. Firmware must latch and timestamp the alarm rather than expect it to mirror a fault edge:

| Fault | Delay before trip / alarm | Setting |
| :--- | :--- | :--- |
| Low pressure | `LO PRESS. DBNCE` (factory **015 s**) then `LPS TRIP` (factory **03 min**, range 03-60 min) | password 678 |
| High pressure | no documented delay | — |
| Pump overload | trips, then **auto-restarts after 15 min** and re-checks current | password 123 (overload current) |

A `LOW PRESSURE!!` message on the display therefore precedes the alarm contact by up to three minutes. Treat display state and alarm contact as two separate observations.

---

### 6.6. Reading `ALARM` Without an Optocoupler — and What That Freed

**Decided 2026-08-27.** `IN_ALARM` moved off PC817 channel 3 to a direct input on
`GPIO 13`, and `LPS` took the vacated channel. Two wires:

```
   ESP32 GND    ----------------- Aster  AUX OP  [ C  ]
   ESP32 GPIO13 ----------------- Aster  AUX OP  [ NO ]

   contact open   -> internal pull-up holds the pin HIGH -> clear
   contact closed -> the two wires are joined           -> fault
```

**Why no optocoupler is needed here.** That terminal is the volt-free `C`/`NO` pair
of the panel's third `HF3FF-012-1ZST` (§6.3). **The relay contact is already the
isolation barrier** — its coil belongs to the Aster, its contacts float free of
the Aster's electronics — so a PC817 behind it would isolate something that is
isolated. Unlike the other four taps, there is no second circuit to keep apart.

**Why the internal pull-up is enough.** It is the one thing the opto path was
genuinely providing that a bare pin does not: §5.2 wets the opto channels at
~4 mA from the 12 V rail through the board's 3 k, where an internal pull-up
manages about **73 µA** — below the `HF3FF`'s datasheet minimum switching load.
Accepted, on three grounds, in increasing order of how much they settle it:

1. **3.3 V is above the fritting voltage** of a sulphide film, so contact closure
   punches through one rather than being blocked by it.
2. **An alarm contact operates a few times a year.** Contact degradation tracks
   operation count; this is not a relay cycling hourly.
3. **The relay sits inside the Aster enclosure** — observed 2026-08-27 — not
   breathing RO-room air. This is the decisive one. Dosing chemistry (sodium
   metabisulphite off-gasses SO₂) is exactly what sulphides silver, and an
   enclosed contact is not exposed to it.

If this input ever does misbehave, the fix is **one 1 kΩ resistor from `GPIO 13`
to 3V3** — ~3.3 mA, which brackets what the opto channels get. It is not fitted,
and it is not needed; it is recorded so nobody has to re-derive it at 2 a.m.

**Noise is handled in firmware, not hardware.** At 45 kΩ this is the
highest-impedance input on the board, on a run that passes contactors. `alarm_active()`
in `app_sensors.c` samples **8 times over ~1.6 ms and requires 6 to agree** — the
same shape the bench sketch used for its AC inputs. Ample against coupled noise,
and nowhere near slow enough to miss a contact that stays closed for minutes.
That mitigation is free, so it is not left as an option.

**Commissioning test, before the Aster is involved at all:** touch the two wires
together. `ALARM` should latch within one poll cycle, the RO room should start
flashing on the dashboard, and a push notification should arrive. That proves the
whole chain — pin, debounce, telemetry, alert — without waiting for a real fault.

**What `LPS` buys on the freed channel.** §6.3's one complaint about `AUX OP` is
that the panel multiplexes every fault onto it: the hub learns that something
tripped, never what. `LPS` **demultiplexes the commonest case**. `ALARM` closed
with `LPS` closed means low feed pressure and the alert says so; `ALARM` closed
with `LPS` open means look at the panel. The firmware sends two different
notifications on exactly that test. Note §6.5's timing caveat still applies — the
display leads the alarm contact by up to the `LPS TRIP` time, factory 3 min.

---

## 7. 4-Channel Relay Output Module (Asterro Float & Level Emulation)

### 7.1. Relay Module to ESP32 Pin Connections

```
  ESP32-S Hub (Control)            5V 4-Channel Relay Module
 +------------------------+        +-------------------------+
 | 5V Rail (Buck Output)  +------->| JD-VCC (Remove Jumper)  |
 | 3V3 (3.3V Logic)       +------->| VCC (Opto Anode)        |
 | GND                    +------->| GND                     |
 | GPIO 27                +------->| IN1 (Relay 1 Control)   |
 | GPIO 23                +------->| IN2 (Relay 2 Control)   |
 | GPIO 18                +------->| IN3 (Relay 3 Control)   |
 | GPIO 19                +------->| IN4 (Relay 4 Control)   |
 +------------------------+        +-------------------------+
```

### 7.2. Relay Contacts to Asterro Terminal Interconnections (Dry Contacts)

Polarity follows Section 6.1 and is **not** interchangeable between terminals. Every de-energized state below is "plant permitted to run", so a hub reset, a firmware crash or loss of the 5V coil rail leaves the panel running on its own real switches — fail-safe by construction.

| Relay Channel | ESP32 GPIO | Target Asterro Terminal | Relay Contacts Used | De-energized (default / boot) | Energized |
| :---: | :---: | :--- | :---: | :--- | :--- |
| **Relay 1** | **GPIO 27** | `TWT FLOTY [ C ]` & `[ NC ]` | `COM` & `NC` | **Closed** = tank not full, plant may run | **Open** = `TW TANK FULL!!` |
| **Relay 2** | **GPIO 23** | `RWT FLOTY [ C ]` & `[ NC ]` | `COM` & `NC` | **Closed** = raw water available | **Open** = `RW TANK EMPTY!!` |
| **Relay 3** | **GPIO 18** | `DOS LVL [ C ]` & `[ NC ]` | `COM` & `NC` | **Closed** = chemical OK | **Open** = dosing low |
| **Relay 4** | **GPIO 19** | Spare — see note below | `COM` & `NC` for `LPS`, `COM` & `NO` for `HPS` | `LPS` form: **closed** = pressure OK. `HPS` form: **open** = pressure OK | trip |

> **As-built 2026-09-13 — Relay 1 behaves the OPPOSITE way to this table, and the table is the specification, not the plant.** Pressing the Relay 1 test **started** the RO. Per the row above, energising it should open the loop and read `TW TANK FULL!!`. Two wiring faults produce exactly that inversion and a meter distinguishes them: the pair landed is `COM`/`NO` rather than the `COM`/`NC` specified, or the relay module is active-HIGH while the firmware defines `RELAY_ON 0`, so what the code calls energising actually drops the coil.
>
> **Why the inversion is dangerous rather than merely wrong.** The contact sits in **parallel** with the float across the same two terminals, and a parallel loop is closed if *either* path is closed. So a closed relay contact shorts the float out completely and the Aster reads "not full" wherever the water is. A five-second test press is long enough for the panel to sample "not full" and begin producing — and with §5.3's fault also present, nothing then stopped it. Neither defect overflows a tank on its own.
>
> **The Relay 1 test button stays enabled, deliberately.** It was disabled in firmware on 2026-09-13 and re-enabled on 2026-09-14 at the operator's instruction: the fault is intermittent (§5.3), and an intermittent fault cannot be characterised with the only tool for exercising it switched off. This is a single-operator private installation - one household, one person with the `/cal` password, physically present whenever the button is used - so the guard was protecting against a risk this site does not carry, at the cost of the diagnosis it needs. The page now labels the inversion instead of preventing it.
>
> Anyone deploying this firmware somewhere with more than one operator, or where nobody is standing next to the tank, should put that guard back.
>
> **This also corrects §0.2**, which records that none of the relay output wires exist yet. At least Relay 1 is landed on `TWT FLOTY`. Re-survey the other three before trusting any row in this table.

> **The 5 s test pulse cannot exercise an interlock slower than itself.** `RELAY_TEST_MS` is 5 s. §6.5 records `LO PRESS. DBNCE` at a factory 015 s, then `LPS TRIP` at a factory 03 min — so the relay releases ten seconds before the debounce would even register, and a "nothing happened" result on `LPS` proves nothing either way. To test `LPS` genuinely, open the loop at the terminal and **hold** it: 15 s to register, up to 3 min to trip, and watch the display rather than the alarm contact (§6.5 — they are two separate observations).

**Testing them in the field: `/cal` has a Relay test panel.** Five buttons — the
four hub relays and the battery-room fan — each of which energises its relay for
**5 s** and then releases it. There is no latch and no off button, deliberately:
energised is the *fault* state on every one of these lines, so a control that
stayed on would let somebody stop the plant by clicking a button and walking
away. Listen for the click and meter `COM`–`NC`; **de-energised is closed**. The
fan is on node `0x04`, so it answers on the next poll rather than instantly, and
a test will not override a fan deliberately forced OFF from the app.

> **Never substitute a hub relay for the real `LPS` or `HPS` switch.** Doing so hands dry-run and over-pressure protection to an ESP32. If a remote stop is wanted, wire Relay 4 **in series** with the real `LPS` loop (`COM`/`NC`, either the switch or the hub can open it) or **in parallel** across `HPS` (`COM`/`NO`, either can close it). The mechanical switch keeps its authority in both arrangements.

```
              Relay Module Dry Contacts                   Asterro Terminal Block
             +-------------------------+                 +-----------------------+
  Relay 1    | COM                     +---------------->| TWT FLOTY [ C  ]      |
  (TWT Float)| NC (Normally Closed)    +---------------->| TWT FLOTY [ NC ]      |
             +-------------------------+                 +-----------------------+
  Relay 2    | COM                     +---------------->| RWT FLOTY [ C  ]      |
  (RWT Float)| NC (Normally Closed)    +---------------->| RWT FLOTY [ NC ]      |
             +-------------------------+                 +-----------------------+
  Relay 3    | COM                     +---------------->| DOS LVL   [ C  ]      |
  (Dos Level)| NC (Normally Closed)    +---------------->| DOS LVL   [ NC ]      |
             +-------------------------+                 +-----------------------+
```

---

## 8. 240V AC Optocoupler Modules (HPP & RWP Contactor Monitoring)

```
  240V AC Side (From Contactor)           240V AC Opto Module          ESP32 Hub
 +-----------------------------+        +---------------------+       +-----------+
 | Switched Phase (e.g. Coil A1)+------->| L                   |       |           |
 | Neutral (e.g. Coil A2)      +------->| N                   |       |           |
 +-----------------------------+        |                 VCC |<------+ 3V3 (3.3V)|
                                        |                 GND +------>| GND       |
                                        |                 OUT +------>| GPIO 34/35|
                                        +---------------------+       +-----------+
```

**The `VCC` wire is not optional, and it is the failure point.** This module is
not a bare optocoupler. Its output side carries a **47 k pull-up from `OUT` to
`VCC`**, silkscreened `47K VCC`, and the input side rectifies (`MB6S`), clamps
(5.1 V zener) and smooths (100 µF) the mains before driving the opto LED. So:

* `VCC` on 3V3 is what makes `OUT` idle high. **No external pull-up is needed** —
  the "outstanding 10 kΩ retrofit" this document and phase-B spec §3.5 carried
  until 2026-08-27 was a misreading of the part.
* If `VCC` or `OUT` loses continuity the pin floats, and `digitalRead` reports
  that as `OFF` — identical to a healthy module seeing no mains. **This has
  already happened once on this build** (broken wire at the module).
* Because the input is smoothed, `OUT` should be *steady* low with mains
  present, not a 100 Hz pulse train. Phase-B spec §5.4 assumed a pulse train;
  that is re-opened pending measurement.

> **Measured 2026-08-28, and the withdrawn resistor is half-rehabilitated.**
> `probeACInput()` on real hardware reports **HPP 2693-3134 mV** and
> **RWP 2924-3134 mV** at idle, not the ~3300 mV steady that a 3.3 V pull-up
> implies. The cause is source impedance: the module's 47 k is too stiff to
> replenish the ESP32 ADC's sampling capacitor, so the reading sags and jitters.
> Espressif's guidance is to keep ADC source impedance under about 10 k.
>
> **This does not restore the "defect".** §1 is still right that no external
> pull-up is *needed* for the optocoupler — the module supplies its own, and
> nothing about that was wrong. What is new is a different and unrelated reason
> to want a part there: ADC accuracy, not contact wetting.
>
> **It works as-is.** 2693 mV clears the 2500 mV idle threshold, and with mains
> present the pin sits near 0 V so active detection has enormous margin. But the
> idle margin is ~190 mV rather than the ~800 mV intended.
>
> **Cheapest hardening, if these channels ever read erratically: one 100 nF from
> each of `GPIO 34` / `35` to GND.** A capacitor is the better fix than a stronger
> pull-up here because it supplies the sampling charge without shifting the DC
> level — the thresholds stay where they are. A parallel 10 k would also work and
> would firm up the level, at the cost of re-tuning `AC_IDLE_ABOVE_MV`.

**Validated 2026-08-27.** Both channels read correctly against live contactors, with the sketch's existing 5 ms filter — which also retires the 25 ms rewrite proposed in phase-B spec §5.4 (see that section). The earlier floating reading was the broken wire at the module, not this design.

**Verify with `probeACInput()`**, which the hub sketch runs every cycle. GPIO 34
and 35 are `ADC1_CH6`/`CH7`, so it reads actual millivolts and prints the min/max
spread over a full mains cycle — the only way to tell the three states apart:

| Reading | Means |
| :--- | :--- |
| `~3300-3300 mV` | Idle. Pull-up alive, `VCC` and `OUT` intact. |
| `0-0 mV` | Mains present, smoothed as expected. |
| swings `0` to `~3300` | Mains present but pulsing — spec §5.4's filter fix is needed after all. |
| stuck mid-scale | **Floating.** Check `VCC` and `OUT` continuity at the module. |

---

## 9. Remote Arduino Nano Tank Nodes (0x02 RWT, 0x03 TWT)

**Node 0x02 (RWT) is the end of the bus**, and it still carries **no terminator** — nor does any other node. See §12.3: this bus has no bias network and does not tolerate one.

```
                                  12V DC CAT5e Power Bus
                                            |
                                            v
                             +------------------------------+
                             | LM2596 / Mini560 Buck Module |
                             | Input: 12V DC | Output: 5.0V |
                             +--------------+---------------+
                                            |
                                            +-- +5V DC ------+
                                            +-- GND ---------+----------+
                                                             |          |
 +-----------------------------------------------------------v----------v-+
 |                            ARDUINO NANO (ATmega328P)                   |
 |  - 5V Pin  <-- +5V Buck Output                                         |
 |  - GND Pin <-- Common Ground                                           |
 +------+------------+-------------+-------------+-------------+----------+
        |            |             |             |             |
      Pin D2       Pin D3        Pin D7        Pin D8        Pin A0 / A1
     (Soft RX)   (Soft TX)     (US TRIG)     (US ECHO)     (Hardware Address)
        |            |             |             |             |
 +------v------------v------+ +----v-------------v----+ +------v----------+
 |    XY-485 MODULE         | |   AJ-SR04M MODULE     | | ADDRESS JUMPERS |
 | RXD --> D2               | | TRIG --> D7           | | see 9.1 below   |
 | TXD --> D3               | | ECHO --> D8           | | A0 -> GND or open|
 | VCC --> 5V (from Buck)   | | VCC  --> 5V (from Buck| | A1 -> GND or open|
 | GND --> GND              | | GND  --> GND          | +-----------------+
 | A+  --> RS485 Bus (A+)   | +---------+-------------+
 | B-  --> RS485 Bus (B-)   |           | (Coaxial Cable)
 +--------------------------+           v
                               +-----------------+
                               | Waterproof      |
                               | Transducer Head |
                               +-----------------+

        Water quality pair (9.5) - both probes in the same water, both or neither
        |
      Pin D4                      Pin D5          Pin A6
     (1-Wire)                   (TDS VCC)        (TDS AOUT)
        |                           |                |
   [ 4k7 to +5V ]                   |                |
        |                           |                |
 +------v-------------------+ +-----v----------------v---------------------+
 |  DS18B20 (waterproof)    | |  TDS METER BOARD (DFRobot-style, analog)   |
 | YELLOW DATA --> D4       | | VCC  --> D5  (GPIO-powered: on only while   |
 | RED    VDD  --> 5V       | |               sampling, ~10 % duty, 9.5.2)  |
 | BLACK  GND  --> GND      | | AOUT --> A6  (0-2.3 V)                      |
 +--------------------------+ | GND  --> GND                                |
                              +---------------------------------------------+

        Pressure transducer provision (9.4) - fit the headers, leave them empty
        |
      Pin A2                          Pin A3
     (4-20 mA sense)                 (fitted?)
        |                                |
 +------v-------------------------+ +----v--------------------------------------+
 |  J-LOOP  (3-pin)               | |  J-PRESS (2-pin)                          |
 | 1: +12V --> transducer +       | | 1: A3   (INPUT_PULLUP)                    |
 | 2: loop return, [100R] to GND, | | 2: GND                                    |
 |    then [1k] --> A2            | | Shunt fitted = transducer present, node   |
 | 3: GND                         | | reports RANGE - head and ignores D7/D8.   |
 +--------------------------------+ | Open = A2 is never read.                  |
                                    +-------------------------------------------+
```

#### Tank node pin allocation (0x02 and 0x03 are wired identically)

Authoritative for the tank nodes; the `#define`s at the top of
`firmware/ro_node/ro_node.ino` must agree with this table.

| Nano pin | Firmware name | Direction | Connects to | Section |
| :---: | :--- | :---: | :--- | :---: |
| `D2` | `PIN_RS485_RX` | in | XY-485 `RXD` (SoftwareSerial) | 12 |
| `D3` | `PIN_RS485_TX` | out | XY-485 `TXD` (SoftwareSerial) | 12 |
| `D4` | `PIN_WATER_TEMP` | in/out | DS18B20 `DATA` (yellow), **4.7 kΩ pullup to +5 V** | 9.5 |
| `D5` | `PIN_TDS_POWER` | out | TDS board `VCC` — driven, not tied to +5 V | 9.5.2 |
| `D7` | `PIN_US_TRIG` | out | AJ-SR04M `TRIG` | 9.0 / 9.3 |
| `D8` | `PIN_US_ECHO` | in | AJ-SR04M `ECHO` (5 V logic, no divider on a Nano) | 9.0 / 9.3 |
| `D13` | `PIN_LED` | out | Onboard LED — blinks on each answered poll | — |
| `A0` | `PIN_ADDR_0` | in, pullup | Address jumper bit 0 → GND or open | 9.1 |
| `A1` | `PIN_ADDR_1` | in, pullup | Address jumper bit 1 → GND or open | 9.1 |
| `A2` | `PIN_PRESS_SENSE` | analog in | `J-LOOP` pin 2 — 4-20 mA loop across the 100 Ω sense resistor | 9.4 |
| `A3` | `PIN_PRESS_FIT` | in, pullup | `J-PRESS` shunt to GND = transducer fitted, ultrasonic ignored | 9.4 |
| `A6` | `PIN_TDS_SENSE` | analog in | TDS board `AOUT`. Analog-only pin, no digital function to lose | 9.5.2 |
| `5V` | — | — | Buck output. Feeds XY-485, AJ-SR04M, DS18B20 `VDD`, the 4k7 pullup | 2 |
| `GND` | — | — | Common: buck, every module, both probes, RS485 `GND` conductor | 12.1 |

Free: `D6`, `D9`–`D12`, `A7`. `A4`/`A5` are I2C — the SHT30 on 0x04 (§10) and the
OPT3004 ambient light sensor on 0x02 (§9.6). Nothing on 0x03 uses them yet.
`D0`/`D1` are the hardware UART and stay a debug port (115200) on every node.

### 9.0. AJ-SR04M Sensor Notes (applies to every ultrasonic node and the hub's dosing sensor)

The sensors in hand are **AJ-SR04M**, not JSN-SR04T. Electrically interchangeable for our purposes — 5 V supply, 5 V `ECHO` needing the divider, ~20 cm blind zone, `pulseIn` timeout of 35000 µs still covering the useful range — with two board-specific gotchas:

| Check | Detail |
| :--- | :--- |
| **`R19` mode-select pad must be EMPTY** | Unpopulated selects HC-SR04-compatible **Trig/Echo** mode, which is what the firmware drives. A resistor fitted there (47 k / 120 k / 200 k) puts the board into one of its **UART** modes, where it either streams frames unasked or waits for a `0x55` command — and `pulseIn` on `ECHO` then reads nothing at all. Inspect the pad before wiring; a board that measures zero every time is almost always this, not a wiring fault. |
| **Trigger pulse width is a tuning knob** | The firmware issues the nominal **10 µs** `TRIG` pulse. Some AJ-SR04M batches are unreliable at exactly 10 µs and want **20 µs**. If a node returns intermittent zeros or wild outliers with the pad confirmed empty, widen the pulse before suspecting the transducer. Keep it as a named constant, not a magic number. |
| **A ~35.3 ms echo pulse means "too close", not "far away"** | With a target inside the ~200 mm blind zone the module holds `ECHO` high for a fixed **~35.3 ms** rather than not pulsing at all. Converted naively that reads as **~604 cm**, which looks like a confident long-range measurement and is the opposite. Our `US_TIMEOUT_US` is 35 000 µs, so `pulseIn` gives up 263 µs before that pulse ends and correctly returns 0 — the firmware reports no echo where a bare sketch would report 604 cm. **A steady 604 cm from a test sketch means the sensor cannot range, usually because a hand, a cable or a bench edge is inside 20 cm.** Established 2026-09-05. |
| **A steady ~600 µs echo, once per ping, with nothing behind it — on a node, never on the hub** | `pulseIn()` on the ATmega counts loop iterations, not time. Every byte on the shared bus (polls and replies for the *other* nodes included) runs the SoftwareSerial RX interrupt for ~1 ms with interrupts off, and those iterations are never counted: a 6.4 ms echo came back as ~600 µs, fell inside the blind zone and was refused. `US_DEBUG` shows it as `d1` with **no second pulse** in the remaining window — a real near-field artifact would still have the true echo behind it. `pingOnce()` now calls `stopListening()` for the ≤35 ms of the ping; the hub's driver times with `esp_timer` and was never affected, which is why the dosing sensor read a steady 452 mm through the whole hunt. Trigger width and sensor supply were investigated first and cleared. |

**Verified 2026-08-25:** `R19` inspected on **all four sensors** and **empty** on each — Trig/Echo mode, which is what the sketches drive. So a zero reading on this build is wiring, power, or the blind zone, not the mode pad. Check the pad again on any sensor added later; batches differ.

Range: 20–600 cm nominal, realistically dependable to ~4–4.5 m on a flat water surface. That covers all three tanks. The 3.5 m ground sump is inside the figure but with less margin than the datasheet implies — see phase-B spec §7.1, which is already tracking the sump sensor choice as an open decision.

### 9.1. Address Jumper Truth Table (authoritative)

Published here first; `firmware/ro_node/ro_node.ino` carries the same table and `docs/check_addrmap.py` fails the build if the two ever diverge:

```c
bit0 = (digitalRead(A0) == HIGH) ? 1 : 0;   // INPUT_PULLUP: open = 1, jumpered to GND = 0
bit1 = (digitalRead(A1) == HIGH) ? 1 : 0;
raw  = (bit1 << 1) | bit0;
return ADDR_MAP[raw];                       // the table below is the lookup;
                                            // 0b00 is UNASSIGNED, not 0x04
```

| `A1` | `A0` | raw | Node ID | Role |
| :---: | :---: | :---: | :---: | :--- |
| **GND** | open | `0b01` | **`0x02`** | RWT (end of bus — no terminator, §12.3) |
| open | **GND** | `0b10` | **`0x03`** | TWT (the board with the pressure-transducer header) |
| open | open | `0b11` | **`0x04`** | Battery Room climate + fan (Pro Mini, §10). Also the unjumpered default |
| **GND** | **GND** | `0b00` | **unassigned** | Refuse to join the bus — see below |

The mapping is a **lookup table written from the observed hardware**, not an arithmetic identity. The three built boards already carried three distinct jumper codes, so the codes were kept and the table was written around them (§9.2). This is exactly what phase-B spec §3.7 prescribed.

```c
// common/protocol.h  --  raw = (A1 << 1) | A0, INPUT_PULLUP: open = 1, GND = 0
static const uint8_t ADDR_MAP[4] = {
  0x00,   // 0b00  both GND    -> unassigned, do not join the bus
  0x02,   // 0b01  A1 to GND   -> RWT
  0x03,   // 0b10  A0 to GND   -> TWT (pressure-header board)
  0x04,   // 0b11  both open   -> Battery Room, climate + fan relay
};

uint8_t nodeIdFromJumpers(bool a0_high, bool a1_high) {
  return ADDR_MAP[((a1_high ? 1 : 0) << 1) | (a0_high ? 1 : 0)];
}
```

A node decoding `0x00` must **not** transmit — hold in a fault state and blink the LED. Guessing an address is how you get two boards answering the same poll. Grounding both jumpers is therefore also the deliberate way to bench a spare board while it is physically on the bus.

> The table previously published here had `0x01`/`0x02` swapped, labelled both-grounded `0x03`, and omitted `0x04`. The original bringup decoder returned `raw` directly with a special case for zero, which matched no assignment. Both are superseded by `ADDR_MAP` above. Phase-B spec §3.7 is closed by this.

**Address `0x01` no longer exists in any form** — the dosing sensor moved onto the hub (§13), and no jumper combination produces it.

**The address also selects the node's personality** (spec §4): `0x02`/`0x03` run the ultrasonic build, `0x04` runs climate + fan relay. A misjumpered node therefore doesn't just answer to the wrong ID — it runs the wrong hardware profile and publishes plausible-looking wrong data.

### 9.2. As-Built Jumper Audit (2026-08-25, tank roles corrected 2026-09-11)

The jumpers are staying as they are. `ADDR_MAP` (§9.1) was written to fit them, so **no board needs rewiring**:

| Board | `A0` | `A1` | raw | Resolves to | Action |
| :--- | :---: | :---: | :---: | :---: | :--- |
| Nano #1 | **GND** | open | `0b10` | `0x03` TWT | Label TWT. This is the board with the pressure-transducer header soldered. **No 120 Ω** (§12.3). |
| Nano #2 | open | **GND** | `0b01` | `0x02` RWT | Label RWT. End of the bus, but **still no 120 Ω** — §12.3. |
| Pro Mini (Battery Room) | open | open | `0b11` | `0x04` Climate | Label Battery Room. **No change** — leave both pads unconnected. |

> **Corrected 2026-09-11, before either tank node was fitted.** The two tank rows
> were the wrong way round. Nano #1 is the only one of the two with the
> pressure-transducer header soldered, and that header is what fixes it as the TWT
> board — but its `A0`-to-GND code resolved to `0x02` RWT. Caught on the bench by
> unplugging it and watching `0x02` go offline rather than `0x03`.
>
> Fixed by swapping the two tank entries in `ADDR_MAP` (§9.1) and reflashing both
> Nanos, not by moving a jumper: the jumper is the soldered thing and the identity
> is the free one. That is the same trade §9.1 made when the table was first
> written around the boards, applied a second time in the same direction.
>
> **The 120 Ω terminator was never fitted** — confirmed 2026-09-11, both boards
> still on the bench. It never will be, either: the one time it was tried, on
> 2026-09-12, the whole bus went dark. Termination is off the table on this bus
> until somebody adds bias to go with it, and §12.3 is the section that explains
> why. Neither Nano gets a resistor.
>
> **Both tank Nanos must be reflashed together.** A board still running the old
> table answers to the other one's address, and two nodes answering one poll is
> the collision this section exists to prevent. Confirm each by its boot print
> before bussing.

Why software rather than the soldering iron: the three codes were already distinct, so there was nothing to disambiguate — only a table to write. It avoids lifting a pad on the Pro Mini's inner pads, avoids touching a node that may already be sealed in its enclosure, and puts the assignment in the one place spec §3.1 says addressing belongs.

**The cost, stated plainly:** the unjumpered default is now `0x04` rather than a tank node. A fresh board dropped on the bus claims to be the Battery Room. That is *louder* than the old failure — two nodes answering the same poll produces immediate CRC/collision errors, where a duplicate tank level produces plausible wrong data nobody notices — but it does mean **any new node must be jumpered before it is bussed**, not after.

**If the boards are ever re-jumpered instead, `ADDR_MAP` must change in the same commit.** One authoritative table; a second person re-deriving jumpers from a stale one is precisely the defect class §3.1 exists to prevent.

Confirm by boot print before bussing: each node prints its detected ID at startup. Read all three.

---

### 9.2.1. As-Measured Tank Geometry — fill this in on site

`full` and `empty` live in NVS as two bare millimetre figures. They lose the
measurements they were derived from, so if a sensor is ever remounted or replaced
nobody can recompute them without going back up to the tank. Write the raw numbers
here instead.

**Three heights per tank, and take all three from the inside floor.** One datum
means every value is a subtraction and no gap goes unrecorded. Mixing references —
"bottom outlet to overflow" plus "floor to face" — leaves the height of the bottom
outlet above the floor unmeasured, and the two figures then cannot be combined.

```
   S = floor -> transducer FACE      (not the roof slab, not the bracket)
   B = floor -> bottom outlet        (the level below which there is no usable water)
   W = floor -> overflow outlet      (the maximum water level)

   empty = S - B        0% when the bottom outlet runs dry
   full  = S - W        100% at the overflow
```

Measuring to the FACE rather than to the roof means the transducer's protrusion is
already accounted for — one fewer number to record and to get wrong.

**`W - B` is the usable depth**, and it is a free cross-check: if it does not match
the tank's nominal capacity, one of the three measurements is wrong.

| Tank | S: floor → face | B: floor → bottom outlet | W: floor → overflow | `full` = S−W | `empty` = S−B | Usable depth W−B | Measured |
| :--- | ---: | ---: | ---: | ---: | ---: | ---: | :--- |
| RWT `0x02` | 1000 | 50 | 750 | **250** | **950** | 700 | 2026-09-12 — see note on `S` |
| TWT `0x03` | 1000 | 0 | 650 | **350** | **1000** | 650 | 2026-09-12 |
| Dosing (hub) | 530 | *lance foot — unmeasured* | *no overflow; fill line 280* | 250 | 540 *(= drum floor; see below)* | — | 2026-09-06, drum |
| Sump `0x05` | | | | | | | Phase 2 |

> **Where the 2026-09-12 figures came from.** Reported from site: TWT is a 1 m
> tank with its overflow pipe at 650 mm; RWT is a Sintex-type tank of *about* 1 m
> with 750 mm to the overflow. `S` was confirmed as measured to the transducer
> **face** on both, so the table is usable as it stands.
>
> **The one soft number is RWT's `S`**, given as "around" 1 m — and RWT is also the
> tank with no slack. `full = S - 750`, so 1000 yields 250 and the refusal
> threshold is 200: **RWT tolerates `S` being wrong by 50 mm and no more.** TWT,
> at `S - 650`, has 150 mm to give. One pass with a tape on the RWT face is worth
> more than any of the arithmetic above; if it comes back under 950, fit the
> stand-off rather than shrinking the number.
>
> **`B`, reported 2026-09-12:** RWT's bottom outlet is **50 mm** above the floor;
> TWT's is **at floor level**, so `B = 0` and its `empty` collapses to `S`. Both
> now need only `S`, and each reduces to one subtraction:
>
> ```
>    RWT 0x02:   full = S - 750      empty = S - 50
>    TWT 0x03:   full = S - 650      empty = S
> ```
>
> **Cross-check, and it does not depend on `S`:** `empty - full` is `W - B`, the
> usable depth, so whatever the face measures at, the saved pair *must* come out
> **700 mm apart on RWT and 650 mm apart on TWT**. If it does not, `S` was applied
> to only one of the two.
>
> **The shipped defaults now carry these figures** (`app_cal.c:29-30`), so a hub
> whose NVS is wiped comes up reading plausibly instead of on placeholders. They
> previously held `empty_mm = 1500` — a distance below the floor of a 1 m tank, so
> neither gauge could reach 0%. `/cal` still overrides both, and a value typed
> there wins over anything compiled in.
>
> **RWT is the one to check first.** At `S = 1000` its `full` is **250 mm, just
> 50 mm clear of the 200 mm blind zone**, and `cal_set_tank()` hard-refuses
> anything under it (`app_cal.c:212`) — so if the RWT face turns out to sit more
> than 50 mm below the rim, the calibration will not save and that tank has no
> level at all. A Sintex lid boss is exactly the fitting that eats those 50 mm.
> Per the rule below, the fix is a stand-off, not a smaller number. Note also that
> 250 mm leaves RWT with no usable band above the overflow — everything from 200
> to 250 mm reads a flat 100%, so "full" and "overflowing" are the same reading.
> TWT's 350 mm keeps 150 mm of headroom and does not have this problem.

**Check before saving: `full` must be at least 200 mm.** That is the blind zone, so
the face has to sit at least 200 mm above the overflow outlet. If it does not, the
top of the scale is unusable and the fix is a stand-off that raises the sensor, not
a number typed into `/cal`.

> **The dosing drum does not have a `W` or a `B`, and that is not a gap to fill in.**
> Confirmed on site 2026-09-12: it is a plain drum — **no auto-fill, no overflow
> drain, no bottom outlet** (`images/hardware/dosing_drum_and_hpp.jpg`). The pump
> draws through a **suction lance dropped in through the lid**. So for this row
> only, the two columns re-read as:
>
> * **`W` is a decision, not a fitting.** Nothing stops an overfill hydraulically,
>   so the fill line is set by the *sensor*: `full` must clear the 200 mm blind
>   zone, and the shipped 250 mm means "fill to 250 mm below the lid" (= 280 mm of
>   liquid in a 530 mm drum). Fill past it and `levelPercent()` reads 100% down to
>   250 mm, then returns **255 — no level, shown as a fault** — under 200 mm
>   (`app_cal.c:429`). The gauge goes blank exactly where an overfill starts, and
>   as the comment there says, that same band is where a **fouled face** reports.
>   On this drum the two are indistinguishable. That is the argument for the
>   bracket in §9.3, not just the lost top third.
> * **`B` is the foot of the suction lance, not the drum floor** — that is where
>   the pump loses prime, which is the definition this section already gives for
>   zero. **It has never been measured.** The shipped `empty_mm = 540`
>   (`app_cal.c:31`) is effectively the drum floor (`S` = 530), so 0% currently
>   means "drum empty" rather than "lance sucking air", and the
>   `Dosing chemical low (0%)` alert still fires a little later than it should.
>
> To be clear about the history: **540 is already a correction**, not an oversight.
> Commit `5053b6d` (2026-09-06) moved it from `900`, a figure that assumed an
> external bracket which was never fitted and which made a bone-dry drum read
> ~55% — the alert was unreachable outright. Floor-referenced zero fixed the
> serious half of that. What is left is the residual gap this section's own rule
> names: zero should sit at the lance foot, not the floor. Measure it and set
> `empty = 530 - (floor to lance foot)`. Small, but dosing is the tank where
> being late costs membranes.

**Why zero is the bottom outlet and not the floor.** `empty = S` would put 0% at a
bone-dry floor, which reports usable-looking water that the pump cannot actually
reach. Referencing zero to the bottom outlet instead makes 0% mean "no *usable*
water", which is the number that matters — particularly for RWT, which feeds the
RWP, and for anything that ever informs dry-run detection (§7.2). If a tank's
bottom outlet is level with its floor, `B = 0` and the two definitions coincide.

**Refine opportunistically.** These figures only need to be close enough that the
gauge is not nonsense. `/cal` shows the percentage the current calibration produces
against the live distance, so the next time a tank is visibly near full or near
empty, read the live millimetres and set the matching value. Everything is in NVS
and editable from a phone.

### 9.3. Ultrasonic Mounting, Per Location

Four tanks, four different problems. The sensor is the same part in each; the mounting is what decides whether it works.

**Rules that apply everywhere:**

| Rule | Why |
| :--- | :--- |
| Transducer face at least **200 mm above the highest water level** | That is the blind zone. Water inside it returns nothing, and the node reports `sensor_status = 1` rather than a number — safe, but you have lost the top of the scale exactly where "is it full" matters. |
| Mount **perpendicular** to the surface, pointing straight down | A tilted transducer reflects the pulse away from itself. A few degrees is tolerable; ten is not. |
| Keep the **beam cone clear** — ladders, pipes, ropes, wall seams | The beam is 45–75° wide, so at 3 m it lights up a cone over a metre across. Anything it clips answers *earlier* than the water does, and an early echo reads as a **shorter distance, which the dashboard shows as a fuller tank**. Wrong in the dangerous direction. |
| Mount **away from the inflow** | Broken surface and foam scatter the pulse. Put the sensor over still water, opposite the fill point. |
| Fit a **hood or shade** over the face in closed tanks | Condensation forming on, or dripping onto, the transducer kills echoes. This is the most common cause of a sensor that worked for a month and then stopped. |

> **The beam-cone rule got more important on 2026-08-28, not less.** `levelPercent()`
> used to return "no level" for any distance shorter than the calibrated `full`
> mark. It now returns **100%** for anything between the 200 mm blind zone and
> `full`, because a barrel filled above its mark is a real measurement and
> reporting it as a fault meant the **overflow alert never fired at all** — the
> alert is gated on having a level, so a genuinely overflowing tank was invisible
> exactly when it mattered.
>
> The cost is on this row. An obstruction that answers from **200–299 mm** used to
> read as a *fault*, which is visible and safe. It now reads as a **steady 100%**,
> which is plausible, and it will hold an overflow alert on forever. That is the
> "wrong in the dangerous direction" this table warns about, and the change
> widened the band it applies to by 100 mm at the top.
>
> It is still the right trade — an obstruction anywhere from 300 to 1500 mm
> *already* read as a falsely-full tank, so this extends an existing hazard rather
> than inventing one, and it buys back overflow detection. But it means the beam
> cone must actually be clear, not approximately clear.
>
> **How to tell the two apart, from the console summary:** a real water surface
> ripples, so its distance wanders by a few millimetres and `q` moves around. An
> obstruction is rock-steady — the same distance, `q100`, cycle after cycle, for
> hours. If a tank sits at exactly 100% with an unmoving distance, suspect the
> mounting before believing the level.
| Strain-relieve the captive lead at the tank wall | The transducer hangs on its own cable otherwise, and it will eventually hang crooked — see rule 2. |

**Dosing barrel (~50 L, wired direct to the hub, §13).** The blind zone *is* the design problem here: a 50 L drum is only ~550–600 mm deep, so a sensor sitting on the barrel mouth cannot read the top third — the range you care about when deciding whether to top up. **Mount it on a bracket 250–300 mm above the open top**, not on the rim. **As built 2026-09-06 it is in the lid** of a **530 mm** drum (`images/hardware/dosing_drum_and_hpp.jpg`), so the hub default is `250 mm full / 540 mm empty` and the top ~40 % of the drum reads as blind-zone fault, not as a level. Fill to ~200 mm below the lid, or fit the bracket and recalibrate over the AP.

**RWT (plastic, roof, `0x02`).** The straightforward one. Standard rules, no special measures.

**TWT (concrete, wide, roof, `0x03`) — the wide tank an ultrasonic sensor cannot use.**

On paper this is the easiest tank: a large flat surface, walls far from the beam. **As built it is the hardest**, because the only penetration is a small wire pass-through in the roof slab, **hard against the wall**.

The arithmetic rules it out. The beam is ~45° total, so its radius grows ~0.41 m per metre of depth. A transducer 100 mm from a wall has that wall inside its beam from **0.24 m down**, and from there on the wall answers at a fixed ~260 mm regardless of where the water is. The tank reads permanently near-full — and *stably*, with quality at 100 and no jitter, so nothing in the telemetry looks wrong. A confidently wrong treated-water level is worse than no reading at all.

Three ways out, in cost order:

1. **Core a new penetration away from the wall.** Clearance must exceed `0.41 × (depth from transducer to the lowest working surface)` — for a 1.5 m drop, **≥ 0.6 m from any wall**. Cheapest in parts, most invasive in a concrete roof slab.
2. **Submersible pressure transducer through the existing hole** (phase-B spec §7.1; node wiring and the firmware provision are in §9.4). Geometry stops mattering: it hangs on its cable and reads head. The cable passes a wire hole, but the **22 mm stainless body does not** — budget on opening that hole to ~30 mm with a masonry bit, which is a far smaller job than coring 90 mm. The 12 V the loop needs is already at the node.
3. **Leave TWT on the Aster float alone** and accept no continuous level here. It is, after all, the tank whose float already drives the controller.

**This reorders the procurement question in spec §7.1.** The sump has an open manhole and can take a stilling well with a sensor already owned; TWT cannot. If exactly one pressure transducer is bought, the evidence points at TWT for it, not the sump.

#### If the TWT transducer is fitted — three requirements

**1. The enclosure above the tank must breathe.** The node box on the tank roof is planned airtight, and a gauge transducer references atmosphere through a vent tube running inside its cable. Terminate that tube in a sealed box and its reference becomes a fixed volume of air in the sun:

> `ΔP = P × ΔT/T` — a **20 °C swing is 6.8 kPa, which is ~0.7 m of apparent water** on a 1.5 m tank. Even 5 °C is 173 mm. The level appears to rise each morning and fall each evening, and nothing in the reading looks faulty.

Fit a **membrane breather vent** (Gore-Tex / IP68 M12 type) in the enclosure wall — weatherproof, pressure-equalised — and add a replaceable desiccant sachet inside. At the terminal, **leave the vent tube open**: never crimp it into a gland, seal it in heat-shrink, or pot it in epoxy. This single detail is the difference between a transducer that holds calibration for years and one that drifts within a week.

**2. Size the sensor to the tank, not to the catalogue.** TWT is **~1.5 m** deep. Accuracy is quoted as % of *full scale*, so a 0-5 m unit gives ±25 mm here — ±1.7 % of the span actually used — and on a Nano's 10-bit ADC the whole tank occupies only ~245 counts (~6 mm each). A **0-2 m or 0-3 m variant** of the same sensor costs about the same, gives ±10 mm, and ~2.4 mm per ADC count. Buy for the tank you have.

**3. Hang it 50-100 mm off the floor.** Clear of sediment, and it means the bottom 50-100 mm is below the sensor and simply never measured — which the hub's calibration absorbs the moment you set *empty = now* at the working empty level.

**Sump (concrete, deep, ground floor, `0x05`).** The hard one, and the reason phase-B spec §7.1 is still open. A 3.5 m shaft with a ladder, a riser pipe and rough walls is exactly the geometry that produces early echoes, and the borewell inflow foams the surface while it runs.

Fit a **stilling well** rather than hoping: a ~100 mm PVC pipe hung vertically, open at the bottom, vented at the top, sensor on the cap. The water inside follows the sump but stays still, and the pipe wall stops the beam ever seeing the shaft. A few hundred rupees, and it addresses turbulence and false echoes in one part.

**Cable routing near the PV installation.** The roof array has no string inverters — the DC runs down to the battery room, where every inverter lives. That is also where node `0x04` sits and where the RS485 chain passes on its way to the roof, so the electrically noisy room is the battery room, not the roof. Keep the Cat5e clear of inverter AC and DC runs there, cross at 90 degrees rather than running parallel, and do not share a conduit with the PV strings on their way down. A 4-20 mA loop feeding a 10-bit ADC will show every bit of noise it picks up as jitter in the level.

**Judging any of these from the data, not by argument:** the node reports `raw` alongside the filtered `median`, plus an echo-quality figure. Clean tracking is a median that moves smoothly with quality at 100. False echoes look like a median stepping between two values with quality stuck below 100. Log a day of it before concluding anything about a sensor.

#### Enclosures, per node

The requirements differ by *location*, and two of them are opposites — the roof
boxes must breathe and the battery-room box must not. Getting that backwards is
the expensive mistake, so the reasons are here rather than the rule alone.

| | **`0x02` RWT / `0x03` TWT** (roof) | **`0x04` Battery Room** (indoor) | **Hub** (RO room, indoor) |
| :--- | :--- | :--- | :--- |
| Rating | **IP65/66** | IP55 is enough | none — ventilated is better |
| Material | **UV-stabilised ABS/PC, light colour** | any sealed box | any, but see the mains note |
| Breather | **M12 membrane vent + desiccant** | **none — keep it sealed** | n/a |
| Cable entries | `0x02`: 1× Cat5e + sensor. **`0x03`: see below** | 1× Cat5e + **mains** for the fan | mains + sensor + bus |

**Do not use a kitchen food container on the roof.** The gasket is not UV-rated
and the body crazes and yellows in a season of Guntur sun. Indoors it is fine, and
that is what the hub is in as built.

**Why the roof boxes breathe and the battery box does not.** On the roof a sealed
box turns a gauge transducer's vent tube into a fixed volume of air — requirement 1
above works out the 0.7 m of apparent level that invents, and condensation on a
transducer face is listed in the mounting rules as the commonest slow failure. A
membrane vent holds the IP rating *and* equalises, which is the whole point of the
part. The battery room has no sun, no transducer, and sulphuric acid mist off the
cells: there the sealed box is the protection.

**`0x03` TWT is the one that does not fit a small box.** It is mid-chain, so both
Cat5e land on its terminals (§12.1) on top of the Nano, XY-485, Mini560, terminal
strip, the `J-LOOP`/`J-PRESS` headers §9.4.2 says to fit now, and the desiccant.
Solid-core Cat5e wants ~25 mm of bend radius; two of them plus glands into a
~90 mm internal cavity leaves nowhere to route. Two ways out, either acceptable:

* go up a size — **150 × 110 × 70 mm** or larger for TWT, or
* keep one cable out of the box: join the trunk in a separate junction outside and
  run a single **stub of ≤ 300 mm** into the node. §12.1 allows that length, and
  the bus stays one continuous line.

`0x02` RWT takes one cable and one sensor lead and fits 100 × 100 × 70 mm.

**When you test-fit, leave room for the two things that get laid out last:** the
M12 vent needs a 12 mm hole plus ~20 mm clear inside a wall, and the desiccant
sachet needs somewhere it is not pressed against a board.

**An opaque lid costs nothing.** Reading the XY-485's TX/RX LEDs is how a bus
fault gets localised (§12.3), but `rs485_error_report()` publishes per-node,
per-command failure counts to the dashboard — which is how `0x04/CLIMATE` was
isolated once already, from the ground. Do not pay for a window on a roof.

**Mains inside a plastic box — hub and `0x04`.** Both switch or carry 240 V: the
hub has the HLK-20M12, and `0x04` has the exhaust-fan relay. Tape over a mains
joint is not the termination to leave behind — the adhesive creeps and hardens
with heat, and general-purpose plastic is not flame-retardant. Terminate mains in
**enclosed terminal blocks**, and fit a **gland or strain-relief** at the mains
entry so a pull cannot lift a live conductor off a screw. The hub's box also wants
ventilation holes: the HLK-20M12 dissipates a few watts and a sealed box cooks it.

> **As built 2026-09-13.** Hub: kitchen storage container, ~220 × 155 × 145 mm,
> sides drilled for ventilation, each module zip-tied separately through the
> drillings. Indoor, and acceptable — but it is the box the mains note above is
> written about. RWT/TWT: Globomotive ABS IP65 junction boxes, 100 × 100 × 70 mm,
> three bought; TWT is the one expected to need the next size up or the ≤ 300 mm
> stub. `0x04` is to get a household container, indoors, sealed and unvented.

---

### 9.4. Pressure Transducer Provision on a Tank Node (fitted or not)

§9.3 argues that TWT is the tank an ultrasonic sensor cannot read. This section is
the provision that makes acting on that argument a one-hour job instead of a
redesign: **the node firmware already reads a 4-20 mA loop**, so procuring the
sensor is the only long-lead item. Nothing needs to change on the hub, in the
RS485 protocol, on the dashboard, or in the alerts.

**What is already done, today:**

| Piece | State |
| :--- | :--- |
| Node firmware `fw 1.01` | Reads the loop on `A2` and reports millimetres exactly the way the ultrasonic does. Shipped on **all** node boards — one binary, as ever. |
| Selection | `A3` jumpered to GND. No jumper, and `A2` is never read: an unfitted, floating input cannot invent a level. |
| Hub, protocol, `/cal`, alerts | **Untouched.** See "why the reading is inverted" below — that is what buys this. |
| On the board | Nothing fitted. Two through-holes' worth of parts (§9.4.4) and the loop wiring. |

#### 9.4.1. Why the node reports `RANGE - head`, not head

An ultrasonic sensor measures the **air gap** and its reading *shrinks* as the tank
fills. A submersible transducer measures **head** and its reading *grows*. The hub's
`levelPercent()` — and `cal_set_tank()`, which refuses `empty <= full` precisely to
catch a swapped pair — assumes the first.

So the node subtracts: it reports `PRESS_RANGE_MM - head`. That is still a number
that shrinks as the tank fills, so every consumer downstream keeps working with no
special case anywhere and no second code path to keep in step.

The two figures you type into `/cal` are then **offsets from the sensor's full
scale** rather than air gaps. They are still just "the number the node reports at
this water line", which is exactly what the `/cal` page shows you live — so the
calibration procedure does not change either.

**A useful consequence:** `/cal` is a two-point fit over a reading that is linear in
loop current, so it absorbs the sense resistor's tolerance, the ADC reference error
*and* a wrong `PRESS_RANGE_MM` — the **percentage stays correct** even if those
constants are off. They only need to be right for the raw millimetres to be honest.
The one hard requirement is that `PRESS_RANGE_MM` is **not smaller than the deepest
head the sensor will see**, or the reading clamps into the blind zone and the tank
reports no level at all.
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

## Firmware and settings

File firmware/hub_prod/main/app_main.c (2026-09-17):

/*
 * app_main.c — RO Monitor production hub
 *
 * Structure follows the gate-controller in this workspace: ESP-IDF, RainMaker as
 * a managed component, two OTA slots, BLE provisioning with a static PoP, and
 * remote firmware updates pushed from the RainMaker dashboard. If you can flash
 * the gates over the air, you can flash this the same way.
 *
 * What is different here: this node is almost entirely a *sensor*. Nothing in
 * this firmware moves water. The only thing it actuates is the battery room
 * exhaust fan, over RS485, and even that has a hotter backstop in the node for
 * when this hub goes quiet. Float emulation relays exist on the board and are
 * driven to de-energised at boot and then left alone — that is Phase C.
 *
 * Three consumers of the same state:
 *   - the local dashboard, once a second, over HTTP          (app_web.c)
 *   - the RainMaker cloud and phone app, on change           (here)
 *   - RainMaker push notifications, on threshold crossings   (here)
 *
 * The poll task is the only writer. Readers take a mutex; see hub_state_lock().
 */

#include <inttypes.h>
#include <stdarg.h>
#include <math.h>
#include <stdio.h>
#include <stdlib.h>
#include <string.h>
#include <time.h>

#include "driver/gpio.h"
#include "esp_event.h"
#include "esp_log.h"
#include "esp_mac.h"
#include "esp_timer.h"
#include "esp_wifi.h"
#include "esp_attr.h"
#include "esp_system.h"
#include "freertos/FreeRTOS.h"
#include "freertos/semphr.h"
#include "freertos/task.h"
#include "mdns.h"
#include "nvs_flash.h"

#include <app_network.h>
#include <esp_rmaker_common_events.h>
#include <esp_rmaker_core.h>
#include <esp_rmaker_ota.h>
#include <esp_app_desc.h>
#include <esp_rmaker_scenes.h>
#include <esp_rmaker_schedule.h>
#include <esp_rmaker_standard_params.h>
#include <esp_rmaker_standard_types.h>
#include <esp_rmaker_utils.h>

#include "app_cal.h"
#include "app_gf.h"
#include "app_priv.h"
#include "app_rs485.h"
#include "app_sensors.h"
#include "app_web.h"

static const char *TAG = "app_main";

/* ------------------------------------------------------------ shared state */

static hub_state_t s_state;
static SemaphoreHandle_t s_state_mux;

void hub_state_lock(void)   { xSemaphoreTake(s_state_mux, portMAX_DELAY); }
void hub_state_unlock(void) { xSemaphoreGive(s_state_mux); }
hub_state_t *hub_state(void) { return &s_state; }

/* ---------------------------------------------------------- history ring */

static hist_rec_t s_hist[HIST_N];
static uint16_t   s_hist_head;      /* next slot to write */
static uint16_t   s_hist_count;

uint16_t history_count(void) { return s_hist_count; }

const hist_rec_t *history_at(uint16_t i)
{
    if (i >= s_hist_count) return NULL;
    uint16_t start = (s_hist_count < HIST_N) ? 0 : s_hist_head;
    return &s_hist[(start + i) % HIST_N];
}

/* Called under the state lock, once a minute, from the poll task. */
static void history_push(const hub_state_t *s, uint32_t epoch)
{
    hist_rec_t *r = &s_hist[s_hist_head];
    r->t      = epoch;
    r->rwt    = (int8_t)(s->rwt_online ? s->rwt.pct : -1);
    r->twt    = (int8_t)(s->twt_online ? s->twt.pct : -1);
    r->dos    = (int8_t)s->dosing.pct;
    r->flags  = (s->hpp.running ? 1 : 0) | (s->rwp.running ? 2 : 0);
    r->hpp_da = s->hpp.deci_amps;
    r->rwp_da = s->rwp.deci_amps;
    r->ro_t   = s->ro_room.fault ? INT16_MIN : s->ro_room.temp_deci_c;
    r->bat_t  = (!s->battery_online || s->battery_room.fault) ? INT16_MIN : s->battery_room.temp_deci_c;
    r->sump    = (int8_t)(s->sump_online ? s->sump.pct : -1);
    r->bore_da = s->utility_online ? s->borewell.deci_amps : -1;
    r->smot_da = s->utility_online ? s->sump_motor.deci_amps : -1;
    r->util_t  = (!s->utility_online || s->utility_room.fault) ? INT16_MIN : s->utility_room.temp_deci_c;
    s_hist_head = (s_hist_head + 1) % HIST_N;
    if (s_hist_count < HIST_N) s_hist_count++;
}

/* ------------------------------------------------------------ event log */

static event_t  s_evts[EVENTS_N];
static uint16_t s_evt_head, s_evt_count;

/* Callable from any task: the ring has its own lock so the cloud event handler
 * can log a disconnect without the poll task's mutex. */
static portMUX_TYPE s_evt_mux = portMUX_INITIALIZER_UNLOCKED;

void event_push(uint8_t kind, uint8_t arg, uint16_t a, uint16_t b)
{
    portENTER_CRITICAL(&s_evt_mux);
    event_t *e = &s_evts[s_evt_head];
    e->up_s = (uint32_t)(esp_timer_get_time() / 1000000);
    e->kind = kind; e->arg = arg; e->a = a; e->b = b;
    s_evt_head = (s_evt_head + 1) % EVENTS_N;
    if (s_evt_count < EVENTS_N) s_evt_count++;
    portEXIT_CRITICAL(&s_evt_mux);
}

uint16_t events_count(void) { return s_evt_count; }

const event_t *event_at(uint16_t i)
{
    if (i >= s_evt_count) return NULL;
    uint16_t start = (s_evt_count < EVENTS_N) ? 0 : s_evt_head;
    return &s_evts[(start + i) % EVENTS_N];
}

/* Every boolean the log cares about, in one place, so a new flag gets logged by
 * adding a line here rather than by remembering to at each site. Pumps are NOT
 * here: run_account() logs those, because it has the duration and the amps. */
static void diff_events(const hub_state_t *was, const hub_state_t *now)
{
    #define EDGE(field, on, off, argv) \
        if (was->field != now->field) event_push(now->field ? (on) : (off), (argv), 0, 0)
    EDGE(rwt_online,     EVT_NODE_ON,  EVT_NODE_OFF,  NODE_ADDR_RWT);
    EDGE(twt_online,     EVT_NODE_ON,  EVT_NODE_OFF,  NODE_ADDR_TWT);
    EDGE(battery_online, EVT_NODE_ON,  EVT_NODE_OFF,  NODE_ADDR_BATTERY);
    EDGE(sump_online,    EVT_NODE_ON,  EVT_NODE_OFF,  NODE_ADDR_SUMP);
    EDGE(utility_online, EVT_NODE_ON,  EVT_NODE_OFF,  NODE_ADDR_UTILITY);
    EDGE(alarm_active,   EVT_ALARM_ON, EVT_ALARM_OFF, 0);
    EDGE(lps_active,     EVT_LPS_ON,   EVT_LPS_OFF,   0);
    EDGE(overcurrent,    EVT_OC_ON,    EVT_OC_OFF,    0);
    EDGE(no_production,  EVT_NOPROD_ON, EVT_NOPROD_OFF, 0);
    EDGE(fan_on,         EVT_FAN_ON,   EVT_FAN_OFF,   0);
    EDGE(dark_outside,   EVT_DARK_ON,  EVT_DARK_OFF,  0);
    #undef EDGE
    /* Not an EDGE: this one carries the current it tripped at in `a`, which is
     * the figure somebody setting the dry threshold actually needs and cannot
     * otherwise get - the trip happens while nobody is watching, and the 24 h
     * trend ring is gone by the time they look. The event log keeps it. */
    if (was->bore_dry != now->bore_dry) {
        event_push(now->bore_dry ? EVT_BORE_DRY_ON : EVT_BORE_DRY_OFF,
                   now->bore_dry_why,
                   now->borewell.deci_amps > 0 ? (uint16_t)now->borewell.deci_amps : 0, 0);
    }
}

/* HPP has been on for every one of the last NOPROD_WINDOW_MIN rows and TWT is
 * no higher now than it was then. Reads the ring without the lock: only the
 * poll task writes it and only the poll task calls this. */
static bool no_production_now(const hub_state_t *s)
{
    if (!s->hpp.running || !s->twt_online || s->twt.pct < 0) return false;
    if (s->twt.pct >= ALERT_TANK_FULL_PCT - NOPROD_RISE_PCT) return false;   /* full: nowhere to rise */
    uint16_t n = history_count();
    if (n < NOPROD_WINDOW_MIN) return false;
    const hist_rec_t *then = history_at(n - NOPROD_WINDOW_MIN);
    if (then->twt < 0) return false;
    for (uint16_t i = n - NOPROD_WINDOW_MIN; i < n; i++) {
        if (!(history_at(i)->flags & 1)) return false;                       /* HPP was off somewhere */
    }
    return s->twt.pct < then->twt + NOPROD_RISE_PCT;
}

/* BORE_DRY_BEGIN - lifted and compiled by docs/check_bore_dry.py, so what is
 * tested is what ships. Keep both functions inside the markers. */

/* Borewell has run for every one of the last BORE_DRY_WINDOW_MIN rows, the
 * sump motor was off for all of them, and the sump is no higher now than it
 * was then. Same access rules as no_production_now(): poll task only, no lock.
 *
 * The sump-motor condition is the whole reason this is trustworthy. Borewell
 * in and sump motor out run together in normal operation, and an outflow that
 * matches the inflow leaves the level flat with a healthy bore. Requiring the
 * outlet to have been shut for the entire window means a flat level can only
 * mean nothing came in. */
static bool bore_no_yield_now(const hub_state_t *s)
{
    if (!s->borewell.running || !s->sump_online || s->sump.pct < 0) return false;
    if (s->sump.pct >= ALERT_TANK_FULL_PCT - BORE_DRY_RISE_PCT) return false;  /* nowhere to rise */
    uint16_t n = history_count();
    if (n < BORE_DRY_WINDOW_MIN) return false;
    const hist_rec_t *then = history_at(n - BORE_DRY_WINDOW_MIN);
    if (then->sump < 0) return false;
    const uint16_t run_da  = cal_ct(CAL_CT_BORE)->run_deci_amps;
    const uint16_t smot_da = cal_ct(CAL_CT_SUMP)->run_deci_amps;
    for (uint16_t i = n - BORE_DRY_WINDOW_MIN; i < n; i++) {
        const hist_rec_t *r = history_at(i);
        /* -1 is "no clamp fitted", not "no current": without the clamp there is
         * nothing to judge either motor by, so the window is void. */
        if (r->bore_da < 0 || r->bore_da < (int16_t)run_da)  return false;  /* bore was off */
        if (r->smot_da < 0 || r->smot_da >= (int16_t)smot_da) return false; /* sump was pumping out */
    }
    return s->sump.pct < then->sump + BORE_DRY_RISE_PCT;
}

/* The fast detector: running, and drawing less than the dry threshold for
 * BORE_DRY_DEBOUNCE_S without interruption. Returns the seconds-under counter
 * in *held so the caller keeps it across cycles; any reading at or above the
 * threshold, or the motor stopping, resets it to zero. */
static bool bore_dry_by_amps(const hub_state_t *s, uint32_t dt_ms, uint32_t *held_ms)
{
    const uint16_t thresh = cal_ct(CAL_CT_BORE)->dry_deci_amps;
    if (thresh == 0 || !s->borewell.running || s->borewell.deci_amps < 0 ||
        s->borewell.deci_amps >= (int16_t)thresh) {
        *held_ms = 0;
        return false;
    }
    /* Saturate rather than wrap: a dry pump nobody attends to would roll a
     * uint32 of milliseconds in seven weeks and drop the flag for one cycle. */
    if (*held_ms < UINT32_MAX - dt_ms) *held_ms += dt_ms;
    return *held_ms >= (uint32_t)BORE_DRY_DEBOUNCE_S * 1000;
}
/* BORE_DRY_END */

/* ------------------------------------------------------- run accounting */

/* Per pump: seconds run today, starts today, and the persisted lifetime total.
 * Time is accumulated from the cycle clock, not counted in cycles, so a slow
 * cycle does not under-count. The total is written to NVS on each STOP, which
 * is the moment the figure is final and a few times a day at most. */
typedef struct {
    cal_ct_t which;
    int64_t  last_us;               /* previous accounting instant */
    uint32_t run_ms;                /* today's, sub-second precision */
    /* This run, in MILLISECONDS, for the NVS write on stop. Milliseconds, not
     * seconds, because it used to be `+= dt_ms / 1000` once per cycle: the poll
     * lands a few ms under POLL_CYCLE_MS, so each call truncated ~1 s off a
     * ~2 s tick and this run - and therefore the lifetime total written to NVS,
     * and the duration in the stop event - accumulated at roughly HALF the real
     * rate. Measured on the bench 2026-09-08: today_s climbed 21 s in 21 s
     * while total_s climbed 10 s. today's figure was always right because
     * run_ms already accumulated ms and divided once; this now does the same. */
    uint32_t run_since_start_ms;
    /* How much of run_since_start_ms is already in NVS. The lifetime total used
     * to be written ONLY on the stop transition, which has two consequences that
     * were both visible live on 2026-09-11: a motor that has not stopped yet has
     * contributed nothing to its lifetime figure, and a reboot part-way through
     * a run discards that whole run from the lifetime figure for good. The
     * borewell was reading today_s 40012 against total_s 658 - eleven hours
     * today against eleven minutes ever, which is impossible on its face.
     * "today" survives a reboot because it is restored from the day ledger;
     * lifetime did not, because nothing had written it. */
    uint32_t committed_ms;
    uint32_t da_sum;                /* deci-amps summed over this run, for the log */
    uint16_t da_n;
    bool     was_running;
} run_acct_t;

/* Which pair of event codes a channel logs. A conditional was fine while there
 * were two pumps; with four it books a borewell start as an RWP one. */
static const uint8_t s_run_evt[CAL_CT_COUNT][2] = {
    [CAL_CT_HPP]  = { EVT_HPP_ON,  EVT_HPP_OFF  },
    [CAL_CT_RWP]  = { EVT_RWP_ON,  EVT_RWP_OFF  },
    [CAL_CT_BORE] = { EVT_BORE_ON, EVT_BORE_OFF },
    [CAL_CT_SUMP] = { EVT_SMOT_ON, EVT_SMOT_OFF },
};
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
void app_main(void)
{
    /* Before the banner, so the banner is in it. */
    s_log_next = esp_log_set_vprintf(log_tap);

    ESP_LOGI(TAG, "==========================================");
    ESP_LOGI(TAG, "  RO Monitor — Central Hub  fw %s", esp_app_get_description()->version);
    ESP_LOGI(TAG, "==========================================");
    event_push(EVT_BOOT, (uint8_t)esp_reset_reason(), 0, 0);

    esp_err_t err = nvs_flash_init();
    if (err == ESP_ERR_NVS_NO_FREE_PAGES || err == ESP_ERR_NVS_NEW_VERSION_FOUND) {
        ESP_LOGW(TAG, "NVS full or outdated — erasing and re-initialising");
        ESP_ERROR_CHECK(nvs_flash_erase());
        err = nvs_flash_init();
    }
    ESP_ERROR_CHECK(err);

    s_state_mux = xSemaphoreCreateMutex();
    ESP_ERROR_CHECK(s_state_mux ? ESP_OK : ESP_FAIL);

    /* Sensible starting state: nothing is online until something answers, and no
     * level is known until a calibrated reading arrives. -1 rather than 0, so a
     * tank that has never reported does not render as empty. */
    memset(&s_state, 0, sizeof(s_state));
    s_state.rwt.pct = s_state.twt.pct = s_state.dosing.pct = -1;
    s_state.hpp.deci_amps = s_state.rwp.deci_amps = -1;
    s_state.ro_room.fault = s_state.battery_room.fault = true;
    s_state.sump.pct = -1;
    s_state.borewell.deci_amps = s_state.sump_motor.deci_amps = -1;
    for (int i = 0; i < 3; i++) s_state.borewell.phase_da[i] = s_state.sump_motor.phase_da[i] = -1;
    s_state.utility_room.fault = true;
    s_state.rwt_floty = -1;

    ESP_ERROR_CHECK(cal_init());
    ESP_ERROR_CHECK(sensors_init());
    ESP_ERROR_CHECK(rs485_init());
    /* gf_init() is NOT here. It starts a task that immediately does a
     * getaddrinfo, and app_network_init() is what brings up esp_netif and the
     * lwIP thread - so from here it asserts "Invalid mbox" in
     * tcpip_send_msg_wait_sem() and panics the hub. It is started below,
     * with the rest of the network-dependent startup. */

    app_network_init();

    esp_event_handler_register(RMAKER_COMMON_EVENT, ESP_EVENT_ANY_ID, &rmaker_event_handler, NULL);

    esp_rmaker_config_t rainmaker_cfg = { .enable_time_sync = true };

    /* MAC-suffixed names, the same trick the gate controllers use, so a second
     * hub on the same account is distinguishable without a reflash. */
    uint8_t mac[6];
    esp_read_mac(mac, ESP_MAC_WIFI_STA);
    char node_name[40];
    snprintf(node_name, sizeof(node_name), "RO Plant Monitor - %02X%02X", mac[4], mac[5]);

    esp_rmaker_node_t *node = esp_rmaker_node_init(&rainmaker_cfg, node_name, NODE_TYPE);
    if (node == NULL) {
        ESP_LOGE(TAG, "RainMaker node init failed — aborting");
        abort();
    }
    esp_rmaker_node_add_attribute(node, "Project", NODE_PROJECT);
    esp_rmaker_node_add_attribute(node, "Device Type", NODE_TYPE);
    esp_rmaker_node_add_attribute(node, "Firmware", esp_app_get_description()->version);

    build_node(node);

    /* OTA from the RainMaker dashboard, into whichever of the two app slots is
     * not running. Same mechanism, same dashboard, same workflow as the gates. */
    esp_rmaker_ota_enable_default();
    /* A Reboot control in the app, and nothing else from the system service:
     * a factory or Wi-Fi reset from a phone strands a hub on a roof. Needed
     * because an OTA into 5368ad3 failed for heap (DASHBOARD_AND_RAINMAKER
     * 4.10) and the only reboot available was a walk to the RO room. */
    esp_rmaker_system_serv_config_t sys_cfg = {
        .flags = SYSTEM_SERV_FLAG_REBOOT,
        .reboot_seconds = 2,
    };
    esp_rmaker_system_service_enable(&sys_cfg);
    esp_rmaker_schedule_enable();
    esp_rmaker_timezone_service_enable();
    esp_rmaker_scenes_enable();

    ESP_ERROR_CHECK(esp_rmaker_start());

    /* Static PoP so pairing does not need the serial console. */
    app_network_set_custom_pop("rohub1234");
    err = app_network_start(POP_TYPE_CUSTOM);
    if (err != ESP_OK) {
        ESP_LOGE(TAG, "app_network_start failed: %s", esp_err_to_name(err));
    }

    /* The AP and the web server do not depend on the station connecting — that is
     * the whole point of running both. Start them regardless. */
    /* These run BEFORE nothing and AFTER app_network_start() only because that
     * call no longer blocks - see CONFIG_APP_NETWORK_ASYNCHRONOUS_CONNECTION in
     * sdkconfig.defaults. Without it, provisioning parked app_main here forever
     * and none of the following ever started. */
    start_softap();
    start_mdns();
    /* Here, not up with rs485_init(), and the position is load-bearing: the gf
     * task resolves a hostname on its first tick, and doing that before
     * app_network_init() has created the lwIP mailbox asserts inside
     * tcpip_send_msg_wait_sem() and reboots the hub. It was invisible until a
     * node address was actually stored - gf_poll_one() returns early on an
     * empty address - and then it is a boot loop for exactly the sites that
     * have the feature configured. gf_poll_one() also refuses to touch the
     * network without a station IP, so this ordering is belt AND braces. */
    ESP_ERROR_CHECK(gf_init());
    if (web_start() != ESP_OK) {
        /* Same reasoning as the AP: losing the local dashboard is degraded
         * operation, not a reason to stop monitoring the plant. RainMaker
         * telemetry and the alerts are unaffected. */
        ESP_LOGE(TAG, "local web server failed to start - cloud path unaffected");
    }

    xTaskCreate(poll_task, "poll", 6144, NULL, 5, NULL);
    xTaskCreate(button_task, "button", 2560, NULL, 3, NULL);

    ESP_LOGI(TAG, "==========================================");
    ESP_LOGI(TAG, "  Dashboard : http://%s.local/", MDNS_HOSTNAME);
#if CONFIG_ESP_WIFI_SOFTAP_SUPPORT && AP_MODE_ENABLED
    ESP_LOGI(TAG, "  Fallback  : SSID %s -> http://192.168.4.1/", AP_SSID);
#else
    /* Printed, not omitted. "There is no fallback" is the single most useful
     * thing this banner can say to somebody standing in front of a hub whose
     * router is down, and a missing line says nothing at all. */
    ESP_LOGI(TAG, "  Fallback  : none - LAN only, AP_MODE_ENABLED=0");
#endif
    ESP_LOGI(TAG, "  Calibrate : /cal  (user %s)", CAL_USER);
    ESP_LOGI(TAG, "  Pairing   : RainMaker app, PoP rohub1234");
    ESP_LOGI(TAG, "==========================================");
}

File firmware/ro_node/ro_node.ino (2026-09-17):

/*
 * RO Monitor - RS485 Node Firmware (production)
 *
 * ONE binary for all three Arduino nodes. The A0/A1 jumpers select the address
 * AND the personality (phase-B spec 4):
 *
 *   0x02  Raw Water Tank      Nano       AJ-SR04M ultrasonic, end of bus (no
 *                                           terminator, WIRING.md 12.3)
 *                                           (+ optional TDS/DS18B20 pair, 9.5,
 *                                            + optional OPT3004 ambient light, 9.6)
 *   0x03  Treated Water Tank  Nano       AJ-SR04M ultrasonic, or a 4-20 mA
 *                                           submersible transducer if the J-PRESS
 *                                           shunt is on (WIRING.md 9.4)
 *   0x04  Battery Room        Pro Mini   GY-SHT30-D + exhaust fan relay on D9
 *
 * There is no per-board edit and no per-board sketch: flashing the wrong image
 * onto a board is a failure mode this design simply does not have.
 *
 * Wiring: WIRING.md 9 (jumpers), 9.4 (pressure transducer), 10 (battery room),
 * 12 (chain and terminators).
 * Protocol: RS485_PROTOCOL.md - 0xAA 0x55 ADDR CMD LEN payload CRC_L CRC_H,
 * CRC-16/Modbus over every preceding byte, payload fields big-endian.
 *
 * Serial (115200) stays a debug port on all three boards. RS485 is SoftwareSerial
 * on D2/D3 so D0/D1 remain the FTDI header.
 */

// Wrong-target guard. Compiling this for an ESP32 fails deep inside SoftwareSerial
// with an error that says nothing about the actual mistake.
#if !defined(__AVR__)
#error "ro_node is AVR firmware. Select Arduino Nano, or Arduino Pro or Pro Mini (ATmega328P 5V 16MHz) - not the ESP32."
#endif

#include <SoftwareSerial.h>
#include <Wire.h>

#define FW_VERSION       0x0102   // 1.02, reported by CMD_PING

// Set to 1 only after confirming the board has an Optiboot-class bootloader.
// The old ATmegaBOOT bootloader on some Nano clones does not clear WDRF, so a
// watchdog reset there boot-loops the board until you reflash it over ISP.
#define ENABLE_WATCHDOG  0

// ---------------------------------------------------------------- pins
#define PIN_RS485_RX     2   // XY-485 RXD
#define PIN_RS485_TX     3   // XY-485 TXD
#define PIN_US_TRIG      7   // AJ-SR04M TRIG (tank nodes)
#define PIN_US_ECHO      8   // AJ-SR04M ECHO (tank nodes, 5V - divider on ESP32 only)
#define PIN_PRESS_SENSE  A2  // J-LOOP pin 2: 4-20 mA loop across the 100R sense resistor
#define PIN_PRESS_FIT    A3  // J-PRESS shunt to GND = transducer fitted, ignore the ultrasonic
#define PIN_WATER_TEMP   4   // DS18B20 1-Wire data. NEEDS a 4k7 pullup to +5V
#define PIN_TDS_POWER    5   // TDS board VCC, driven so the probe is not DC-biased 24/7
#define PIN_TDS_SENSE    A6  // TDS analog out. A6/A7 are analog-ONLY on the Nano, so
                             // spending one here costs nothing that could be used otherwise
#define PIN_FAN_RELAY    9   // 1-ch relay IN, ACTIVE LOW (0x04 only)
#define PIN_LED          13  // Onboard activity LED
#define PIN_ADDR_0       A0  // Address jumper bit 0
#define PIN_ADDR_1       A1  // Address jumper bit 1

#define SHT30_I2C_ADDR   0x44
#define OPT3004_I2C_ADDR 0x45   // 7Semi breakout default. Not 0x44: the SHT30 lives on the
                                // battery-room node and this on the RWT node, but they must
                                // never be able to collide if a board is ever re-purposed.

// ---------------------------------------------------------------- protocol
#define PREAMBLE_1       0xAA
#define PREAMBLE_2       0x55
#define RESPONSE_BIT     0x80

#define CMD_PING            0x01
#define CMD_READ_LEVEL      0x02
#define CMD_READ_CLIMATE    0x06
#define CMD_SET_FAN_RELAY   0x07
#define CMD_READ_WQ         0x08   // TDS + water temperature (tank nodes)
#define CMD_READ_LIGHT      0x09   // OPT3004 ambient light, raw result register (0x02 only)

#define MAX_PAYLOAD      32
#define FRAME_TIMEOUT_MS 20   // gap that abandons a half-received frame

// ---------------------------------------------------------------- tuning knobs
// Ultrasonic. AJ-SR04M: ~200 mm blind zone, useful to ~4.5 m on water.
// Widening this to 20 us was tried on 2026-09-05 per WIRING.md 9.0 and changed
// nothing, so it is back at the nominal 10 - same as the hub, same as the bare
// test sketch that behaved correctly. Recorded so nobody re-runs it: the burst
// timing has never been implicated.
#define US_TRIG_WIDTH_US 10

// How many sub-blind-zone echo pulses to step over before giving up on a ping.
//
// pulseIn() returns the FIRST high pulse after the trigger. When a measurement
// is corrupted (see pingOnce, and SoftwareSerial), that pulse is short garbage:
// 2026-09-05 traces showed clusters at ~511 us (88 mm) and ~600 us (101-105 mm),
// all inside the 200 mm blind zone where the module has nothing legitimate to
// report. Accepting one is worse than useless, because four of them outvote one
// true sample in the median window - which is how quality read q80-q100 while
// every published value was junk.
//
// Stepping past them found no real echo hiding behind: a good ping arrives with
// nothing in front of it (d0), a corrupted one has the artifact and nothing
// else - because the "artifact" IS the real echo, undercounted by pulseIn while
// the SoftwareSerial RX ISR steals its loop iterations (bus traffic for the other
// nodes). So this is not the fix - the fix is in pingOnce - but it is kept,
// because refusing an impossible reading is right regardless of why it appeared,
// and the total wait stays bounded by US_TIMEOUT_US.
#define US_MAX_DISCARD   4
#define US_TIMEOUT_US    35000UL // ~6 m of flight time
#define BLIND_ZONE_MM    200
#define WINDOW           5       // rolling median depth, one sample per cycle
#define AGREE_MM         25      // samples this close to the median count as good
#define DEAD_CYCLES      10      // consecutive no-echo cycles before "hardware fault"
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

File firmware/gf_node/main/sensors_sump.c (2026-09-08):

/*
 * sensors_sump.c - the sump node's half of the shared sensors_* interface.
 *
 * Looks down a 3.5 m concrete manhole shaft: a ladder, a riser pipe and rough
 * walls all return an ultrasonic echo, and the borewell inflow foams the
 * surface while it runs. That geometry is exactly what the J-PRESS shunt
 * (gf.h GPIO_PRESS_FIT) exists to route around - read once at boot, never
 * polled again, because a shunt on a bench-tested board does not fall off.
 * Fitted, the node reads a 4-20 mA submersible transducer across the 100R
 * J-LOOP sense resistor instead of pinging.
 *
 * This is the ESP32 rebuild of firmware/ro_node/ro_node.ino's tank-level
 * code (its pingOnce/sampleTank and readPressureOnce/pressureMM). Same
 * rolling median, same blind-zone discard, same agreement-based quality,
 * same dead-cycle fault latch, same 4-20 mA live-zero reasoning - carried
 * over deliberately rather than re-derived, because every one of those
 * numbers came from a field trace on a real echo (ro_node.ino's US_DEBUG
 * history). Deviations from that file, and why, are called out inline.
 *
 * The hub owns calibration - a raw distance or raw microamp reading in,
 * a percentage out. This file reports neither a percentage nor a converted
 * head; that arithmetic does not belong on the node (spec 4.1, gf.h).
 */
#include <stdio.h>
#include "driver/gpio.h"
#include "esp_adc/adc_cali.h"
#include "esp_adc/adc_cali_scheme.h"
#include "esp_adc/adc_oneshot.h"
#include "esp_app_desc.h"
#include "esp_log.h"
#include "esp_rom_sys.h"
#include "esp_timer.h"
#include "freertos/FreeRTOS.h"
#include "freertos/task.h"
#include "gf.h"

#if CONFIG_GF_ROLE_SUMP
static const char *TAG = "sump";

#define BLIND_ZONE_MM   200      /* AJ-SR04M datasheet minimum; below it, an echo is the ladder or riser, never water */
#define US_TIMEOUT_US   35000    /* ~6 m round trip - ample for a 3.5 m shaft */
#define WINDOW          5        /* rolling median depth, one sample per cycle - matches ro_node.ino */
#define AGREE_MM        25       /* samples this close to the median count as good */
#define DEAD_CYCLES     10       /* consecutive no-echo cycles before NO_ECHO */
#define LOOP_SENSE_OHMS 100
#define LOOP_SAMPLES    8
#define PRESS_MIN_UA    3500     /* below 4 mA live-zero: a cut cable or dead supply, not an empty sump */
#define PRESS_MAX_UA    21000    /* above 20 mA: a shorted loop or miswire */

static bool     s_pressure;                  /* J-PRESS shunt read once at boot */
static uint16_t s_win[WINDOW]; static uint8_t s_next, s_filled;
static uint16_t s_median_mm; static uint8_t s_quality; static uint8_t s_n; static uint8_t s_dead;
static uint32_t s_loop_ua;
/* Overwritten by sensors_init() once J-PRESS has been read, and by the first
 * sensors_sample() ~2 s later. NO_ECHO here is only the ultrasonic path's
 * "nothing yet"; a current loop has no echo to miss, so init picks per role. */
static const char *s_status = "NO_ECHO";
static adc_oneshot_unit_handle_t s_adc; static adc_cali_handle_t s_cali; static bool s_cali_ok;

/* One ping, one credible echo or 0. Polled with esp_timer rather than
 * pulseIn() - the ESP32 has no Arduino pulseIn, and esp_timer_get_time() is a
 * free-running 64-bit microsecond counter available at task context, which is
 * everything the busy-wait loops below need. Unlike ro_node.ino's node this
 * one has no RS485 bus to go deaf for, so there is no equivalent of its
 * US_MAX_DISCARD/rs485.stopListening() dance - one pulse read is enough.
 *
 * Sub-blind-zone pulses are discarded here, not passed through: ro_node.ino's
 * hard-won lesson (see its BLIND_ZONE_MM comment) is that in this geometry
 * the first echo is very often the ladder or the riser pipe, not the water,
 * and a short reading that outvotes real samples in the median window is
 * worse than a missed cycle. */
static uint16_t ping_once(void)
{
    gpio_set_level(GPIO_US_TRIG, 0); esp_rom_delay_us(4);
    gpio_set_level(GPIO_US_TRIG, 1); esp_rom_delay_us(20);
    gpio_set_level(GPIO_US_TRIG, 0);
    int64_t t0 = esp_timer_get_time();
    while (gpio_get_level(GPIO_US_ECHO) == 0) {
        if (esp_timer_get_time() - t0 > US_TIMEOUT_US) return 0;
    }
    int64_t rise = esp_timer_get_time();
    while (gpio_get_level(GPIO_US_ECHO) == 1) {
        if (esp_timer_get_time() - rise > US_TIMEOUT_US) return 0;
    }
    uint32_t us = (uint32_t)(esp_timer_get_time() - rise);
    uint16_t mm = (uint16_t)((us * 10UL) / 58UL);
    return mm >= BLIND_ZONE_MM ? mm : 0;   /* sub-blind-zone pulses are artefacts, not water */
}

/* Push one raw sample - 0 included - and recompute the median and quality
 * from whatever is CURRENTLY in the window, rather than maintaining a
 * running valid-count that only ever grows. ro_node.ino's sampleTank()
 * works the same way: every cycle it rebuilds `valid[]` from the whole
 * window, so a run of dead pings evicts old good samples one slot at a
 * time until none are left. Getting this wrong is how a transducer that
 * dies after five good echoes would leave distance_mm/quality latched at
 * the last good reading forever - reviewed in task 10 fix round 1: the
 * earlier version only wrote a slot on a non-zero ping, so s_n could grow
 * but never shrink, and a dead sensor was reported as a live, confident one
 * (the hub's only gate is quality, so a frozen q100 never gets refused). */
static void window_update(uint16_t raw)
{
    s_win[s_next] = raw;
    s_next = (uint8_t)((s_next + 1) % WINDOW);
    if (s_filled < WINDOW) s_filled++;

    uint16_t valid[WINDOW]; uint8_t n = 0;
    for (uint8_t i = 0; i < s_filled; i++) if (s_win[i]) valid[n++] = s_win[i];
    s_n = n;
    if (n == 0) { s_median_mm = 0; s_quality = 0; return; }   /* nothing credible: report nothing, not stale */

    for (uint8_t i = 1; i < n; i++) { uint16_t k = valid[i]; int j = i - 1; while (j >= 0 && valid[j] > k) { valid[j + 1] = valid[j]; j--; } valid[j + 1] = k; }
    s_median_mm = valid[n / 2];

    /* How many of the window agree with the median, as a percent: the hub
     * gates a level under q60 (MIN_LEVEL_QUALITY), same rule as the RS485
     * tank nodes. Percent of the fixed WINDOW depth, not of n: one lonely
     * sample among four timeouts scores q20, not q100 - agreeing with
     * itself is not the same as having been reproduced. */
    uint8_t agree = 0;
    for (uint8_t i = 0; i < n; i++) if ((valid[i] > s_median_mm ? valid[i] - s_median_mm : s_median_mm - valid[i]) <= AGREE_MM) agree++;
    s_quality = (uint8_t)((agree * 100) / WINDOW);
}
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

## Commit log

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2026-08-25 Firmware: address map from the as-built jumpers, battery room climate node
    The addressing decision lived only in the documents; the sketches still
    decoded jumpers arithmetically and disagreed with them.
    - Both node sketches now resolve their ID through ADDR_MAP, written to fit the
    boards as they are already jumpered: 0b01 -> 0x03 TWT, 0b10 -> 0x02 RWT,
    0b11 -> 0x04 Battery Room. No board needs rewiring. 0b00 is "unassigned":
    the node holds off the bus and blinks rather than guessing an address.
    - New promini_battery_node_test: SHT30 over Wire with both CRC-8 bytes checked,
    a local thermostat on D9 (ON 38.0 C, OFF 36.0 C, active-low relay), and
    CMD_READ_CLIMATE 0x06. The fan is the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
    [check_addrmap.py, esp32_hub_test.ino]
2026-08-26 Production node firmware; tank calibration moves to the hub
    One binary for all three Arduino nodes, and the level maths moves to the only
    place it can be changed without a cable.
    - firmware/ro_node replaces the two bringup sketches. The A0/A1 jumpers select
    the address and the personality: 0x02/0x03 ultrasonic, 0x04 climate + fan.
    Nothing to edit per board, so flashing the wrong image stops being possible.
    - Nodes speak the real frame from RS485_PROTOCOL.md 2 - LEN, CRC-16/Modbus,
    the full CMD_READ_LEVEL payload - and the hub test sketch speaks it back,
    with the 100 ms timeout and two retries section 7 specifies.
    - Sensing is scheduled around the poll, never against it: pulseIn bloc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
    [check_frame.py, esp32_hub_test.ino, ro_node.ino]
2026-08-26 Hub: fix the tank report signature, guard the wrong board target
    - reportTankNode took a label while the call sites had already moved to tank
    indices, so the sketch did not build. It now takes the index, records the
    distance for the calibration page, and scales the percentage hub-side; the
    node's level byte is ignored, because nodes no longer compute one.
    - Both sketches carry an #error for the wrong target. Compiling ro_node with
    an ESP32 selected used to fail inside SoftwareSerial.h, which says nothing
    about the actual mistake.
    - Wi-Fi TX back to full power. Throttling it was aimed at a brownout that
    turned out to predate the radio - the same loop happens on the pre-Wi-Fi
    ske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
    [esp32_hub_test.ino, ro_node.ino]
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2026-08-26 Fan policy moves to the hub; node keeps a backstop
    Same principle as tank calibration: the node measures and actuates, the hub
    decides. A fan threshold is a setting people change - 38 C in April is not 38 C
    in December - and it should not need a programmer on a ladder.
    Hub: fanOnDeciC / fanOffDeciC in NVS, editable from the calibration page
    alongside the tank numbers, exposed in /api/cal. It reads CMD_READ_CLIMATE,
    applies hysteresis, and drives the relay with CMD_SET_FAN_RELAY.
    Node: the local thermostat becomes a backstop at 40.0 / 37.0 C, deliberately
    hotter and wider than any hub setting so it never fights policy, and it only
    engages after five minutes with no command. The SHT30 fail-s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
    [esp32_hub_test.ino, ro_node.ino]
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2026-08-26 Hub self-test clicks the battery room fan relay too
    The relay cycling block exercised the hub's own four relays and left node
    0x04's fan relay untouched. Fan policy will never click it on a bench -
    the room sits ~25 C below the 38.0 C ON threshold and the 60 s refresh
    just re-asserts OFF - so a relay that is dead, miswired, or hanging off a
    browned-out Pro Mini looked exactly like a relay that is simply not
    needed yet. Five relays, five clicks, one of them proving the whole
    hub -> RS485 -> node -> coil path in one go.
    Restores to climateFanOn rather than to OFF: if the room genuinely is
    hot, a test must not seal it for the rest of the cycle. Skipped entirely
    when 0x04 is offline, or every c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
    [esp32_hub_test.ino]
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2026-08-26 AC opto pull-up was never missing; measure the pins instead
    The 240V module is not a bare open-collector. Its output side carries a
    47k pull-up from OUT to VCC - silkscreened "47K VCC", visible in
    images/hardware - which is the reason the board has a VCC terminal at
    all, and WIRING.md's own section 8 diagram has shown that terminal wired
    to 3V3 the whole time. With VCC present, pinMode(pin, INPUT) is correct
    and there is nothing to retrofit.
    So the "outstanding hub defect" was a paper defect. It originated in one
    audit row claiming the sketch's hardware-pull-up comment was wrong; the
    comment was right. From there it propagated into spec 3.5, the spec pin
    map, the open-items table, HARDWARE.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
    [esp32_hub_test.ino]
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2026-08-27 CT header on the hub, and a pedestal check to prove it
    Fits the connector now so the bias breakout can be built and verified
    before the clamps land. One 1x5 header: GND, GPIO 36, 3V3, GPIO 39, GND.
    That pin order is deliberate. 3V3 between the two analog pins keeps the
    channels non-adjacent and screens one from the other through C1/C2, a
    ground flanks each analog pin, and the whole thing is a palindrome except
    for pins 2 and 4 - so plugging the breakout in backwards swaps HPP and
    RWP labels and does nothing else. The obvious 3V3-GND-A-A-GND ordering
    puts 3V3 onto a ground pin when reversed and shorts the rail. A header
    that cannot be plugged in destructively needs no key.
    probeCTInput() re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
    [esp32_hub_test.ino]
2026-08-27 Production hub firmware: ESP-IDF, RainMaker, OTA, local dashboard
    Built the way gate-controller is built, on purpose: ESP-IDF, esp_rainmaker
    as a managed component, the same two-slot OTA partition layout, BLE
    pairing with a static PoP. One update workflow now covers both projects -
    push from the RainMaker dashboard, no cable.
    Verified by compiling, not by inspection. idf.py build against IDF 5.4.4:
    1.60 MB, 8% free in the OTA slot, zero warnings from these sources. Two
    defects only a linker would have found:
    - app_main.c was missing driver/gpio.h, which surfaced as 13 errors
    - iram0_0_seg overflowed by 3416 bytes once Wi-Fi, NimBLE, lwIP,
    RainMaker and an HTTP server were all linke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
    [partitions.csv]
2026-08-27 Halve the flash headroom problem: -Os and a gzipped dashboard
    OTA slot free space goes 8% -> 18%, measured on IDF 5.4.4:
    before 1,679,680 B 155,328 B free
    after 1,497,376 B 337,632 B free (-178 KB)
    -Os accounts for ~131 KB of that. RainMaker's build prints "USING O3",
    but sdkconfig confirms CONFIG_COMPILER_OPTIMIZATION_SIZE=y wins, so that
    message was noise rather than an override. The trade is sound here: the
    hot path is a two-second poll loop and one HTTP page, nothing is
    throughput-bound, and flash spent on speed is spent twice because the OTA
    layout holds two copies.
    gzip accounts for the other 46.5 KB - 67,080 bytes of dashboard down to
    19,414. Compressed at BUILD time f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
    [app_main.c, app_web.c]
2026-08-27 Dashboard: flashing fault room, pump currents, concrete TWT
    Alarm. The whole RO room reads as faulted rather than one row in a list.
    The static state carries the fault colour and the pulse sits on top of
    it, in that order deliberately: the file's reduced-motion rule switches
    every animation off, and a fault visible only as a flash would silently
    stop being visible for anyone with that preference set. ~0.9 Hz, under
    the 3 Hz photosensitivity threshold.
    Pump current under HPP and RWP, which turned up a real bug in what I
    committed earlier: the hub was sending "amps":0.0 when no clamp is
    fitted. Zero amps is what an idle pump reads, so a missing clamp looked
    like a stopped motor. It now sends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
    [app_web.c, check_telemetry.py]
2026-08-27 Clamp all three phases on the sump and borewell motors
    Six new CT channels, three per motor. This reverses what spec 7.3 argued
    until now, and the old reasoning is kept rather than overwritten: two
    clamps per motor DO detect single-phasing in every case, because a motor
    that loses a phase draws harder through what remains. That was never
    wrong.
    What the third clamp buys is phase imbalance as a NUMBER instead of an
    inference - largest deviation from the mean of three, as a percentage.
    That is the standard predictive measure for a 3-phase motor, the one that
    trends over a season and maps onto derating and winding wear long before
    anything trips. With two channels you learn that something is w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
    [check_pinmap.py]
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2026-08-27 ALARM goes direct to GPIO 13, freeing PC817 ch3 for LPS
    The Aster AUX OP terminal is the volt-free C/NO pair of the panel's third
    HF3FF, and that relay contact is ALREADY the isolation barrier - its coil
    is the Aster's, its contacts float clear of the Aster's electronics. A
    PC817 behind it isolates something isolated. Two wires do the job: GND to
    the relay common, GPIO 13 to NO, internal pull-up, done.
    I argued against this twice and was wrong twice, which is worth recording
    because the corrections are the useful part. First I claimed a ground-loop
    risk; there is none, for the reason above. Then I claimed the internal
    pull-up's ~73 uA would film over a silver power contact "in months" -
    ove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
    [app_main.c, app_priv.h, app_sensors.c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]
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2026-08-27 Three bugs the first cloud-connected boot exposed
    All three came out of one hardware log, and none would have been found by
    compiling.
    1. report_str() had no change detection. Every other reporter here has a
    deadband; this one published on every 2 s cycle whether the string had
    changed or not, so the log shows "Reporting params: {"RO Plant":
    {"Status":"Idle - TWT 0%"}}" over and over - roughly 43,000 identical
    MQTT messages a day. The same boot prints "MQTT Budgeting initialised.
    Default: 100, Max: 1024", so this is not merely wasteful; it is a node
    that eventually gets throttled.
    2. An alert raised before MQTT connected latched anyway. The dosing-low
    alert fired at 1.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
    [app_main.c]
2026-08-27 Say something when a node goes quiet, and make ALERT_REARM_MS real
    Both came out of "why am I not getting RWT readings in the log", which
    turned out to be a fair question with no answer available in the log.
    RWT is only published when levelPercent() yields a level, so a node that
    stops answering - or answers with a distance outside its calibration -
    produces no parameter update and, in the firmware as written, no log line
    either. Total silence. The bench sketch printed a line per node per cycle,
    which is right for something you sit and watch; this runs for months, so a
    per-cycle line is noise that buries everything else. Logging nothing was
    the wrong end of that trade.
    Now it logs on TRANS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
    [app_main.c]
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2026-08-27 Separate "over-full" from "blind zone" in levelPercent
    Asked whether the dosing blind zone could be treated as 100%. It should
    not be, but the question exposed a real conflation sitting next to it, and
    that fixes most of what was wanted.
    The old branch was:
    if (distanceMM < fullMM) return 255; /* blind zone, or over-full */
    Its own comment admits it. With dosing calibrated full=250 against a
    200 mm blind zone, a reading of 210 mm is not blind at all - it is a
    perfectly good measurement of a barrel filled above its calibrated mark.
    Reporting no-level for that is wrong. Only readings below 200 mm are
    untrustworthy. Now:
    < 200 mm no level genuinely blind
    200-249 mm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
    [app_cal.c, check_frame.py, esp32_hub_test.ino]
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2026-08-27 /cal shows the resulting percentage, not just "measured"
    Prompted by "shall I measure the tanks with a tape so we can roughly
    calibrate the sensors" - yes, and the page was missing the one piece of
    feedback that makes that job possible.
    Calibrating means typing two numbers while standing next to a tank, and
    the only useful check is whether the percentage that comes back matches
    what you can see. The page showed the live millimetres and then the word
    "measured", which says nothing. It now shows the percentage the current
    calibration actually produces, or "no echo", or "no level - out of range"
    so the two failure modes are distinguishable.
    Also states the measuring rule inline, because it is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
    [app_web.c]
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2026-08-29 Pressure transducer provision on the tank nodes
    9.3 already argues that TWT is the tank an ultrasonic sensor cannot read:
    the only roof penetration is hard against a wall, and the beam cone answers
    off that wall at a fixed ~260 mm forever, stably, with quality at 100. This
    makes acting on that argument a swap rather than a redesign - the firmware
    already reads a 4-20 mA loop, so procuring the sensor is the only long-lead
    item left.
    A3 jumpered to GND selects it. Without the jumper A2 is never read, so an
    unfitted, floating input cannot invent a level. One binary still, on all
    three boards.
    The part worth explaining is the inversion. An ultrasonic sensor measures
    air gap and its reading shr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
    [check_frame.py, ro_node.ino]
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2026-08-30 Size the loop resistor against the cable drop, not the datasheet
    Vamsi asked whether the Cat5e drop would bite a 12 V pressure transducer at
    TWT. It does not - but the question exposed that the 150 R I specced two
    commits ago cannot work at any run length, which is worse.
    The drop itself is a non-event. The transducer adds about +5 mA to the trunk
    once the AJ-SR04M it replaces comes off, so 0x03 sees 0.30 V of drop over
    the section 5 assumed 10 m hops, 0.74 V at 25 m, 1.18 V at 40 m. The buck
    regulates from 7 V and never notices.
    The loop notices. What reaches the transducer is what survives the sense
    resistor's burden, and that burden is worst at 20 mA - which is a FULL TANK:
    150 R -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
    [check_frame.py, ro_node.ino]
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2026-09-01 Deployment prep: LAN-only, nagging alerts, OTA that can recover
    One commit rather than three, deliberately: the firmware now reports its git
    description as its version, so a single hash has to identify everything that is
    on the box. Split across three commits, only the last would be nameable from the
    device.
    VERSION IS THE COMMIT
    FW_VERSION "1.0.0" is gone. CMakeLists sets PROJECT_VER from
    `git describe --always --tags --dirty`, and the boot banner, the RainMaker
    "Firmware" attribute and the dashboard footer all read it back out of the app
    descriptor, so nothing can drift from the code.
    RainMaker refuses an update whose version equals the running one (the memcmp in
    esp_rmaker_ota.c) but n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
    [app_main.c, app_priv.h, app_web.c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]
2026-09-01 The boot banner still advertised the AP it just disabled
    Flashed 036f30b and the closing banner printed
    local AP disabled (AP_MODE_ENABLED=0) - dashboard and /cal are LAN only
    ...
    Fallback : SSID RO-HUB -> http://192.168.4.1/
    four lines apart. The second is now false, and it is the line somebody reads
    when the LAN is the thing that has failed - which is exactly the moment they
    would go looking for an access point that is not there.
    The line stays rather than being compiled out. "Fallback: none" is the most
    useful thing this banner can tell someone standing in front of a hub with a dead
    router; an absent line tells them nothing and reads like an older firmware.
    Co-Authored-By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
    [app_main.c]
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2026-09-01 CMD_READ_WATER_QUALITY: TDS and water temperature, per tank
    Ready for the probes when they arrive. Nothing runs until the hardware is
    fitted, and every node today reports "not fitted" and does nothing else.
    WHAT IT MEASURES, AND WHY IT IS A PAIR
    Not TDS. Salt rejection:
    rejection % = (RWT ppm - TWT ppm) / RWT ppm
    Permeate TDS rising is not a fault on its own - it rises when the FEED rises,
    which is a fact about the borewell, not the plant. The ratio removes that, and a
    falling rejection percentage is a failing membrane whatever the source water
    does. That needs both tanks, which is why the probes come in twos.
    MILLIVOLTS, NOT PPM
    The node reports raw probe millivolts and a temperat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
    [app_cal.c, app_main.c, app_priv.h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]
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2026-09-01 "Node offline" read as if the hub was the node that was offline
    Vamsi: "app says RO room is node offline, but the HUB is on and whole device
    is on". He is right, and the message was mine.
    The string means one of the three RS485 nodes is not answering - 0x02, 0x03 and
    0x04 are all unwired, so all three. It was already ambiguous when this device was
    called "RO Plant". Renaming the device to "RO Room" made it actively wrong: read
    on that card it says the RO Room hub is down, which is the one thing it cannot
    possibly mean, because the hub is what published the message.
    It now names them - "Waiting for RWT TWT Battery" - which is unambiguous about
    who is waiting and is also the actionable half.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
    [app_main.c]
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2026-09-01 Three things the live dashboard was reporting wrongly
    Fetched /api/telemetry off the running hub at 192.168.1.180 rather than trusting
    the code, and it said:
    "rssi":0, "reset_reason":"Power on"
    "rwt":{"state":"SENSOR_ERROR","sensor":"OK"}
    "battery_room":{"state":"SENSOR_ERROR","age_s":9999}
    RSSI AND RESET REASON WERE NEVER WIRED
    Both were literals in the format string - `0` and `"Power on"` - written as
    placeholders and never replaced. So the header reported a signal strength of
    0 dBm, which is not a possible reading, and the footer claimed a clean power-on
    after every crash the hub has ever had.
    The reset reason is the one that costs something. PANIC and BROWNOUT are exactly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
    [app_web.c]
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2026-09-01 False alerts: filter the sensor, then confirm the condition
    Four "Dosing chemical low" notifications in forty minutes - 15%, 19%, 13%, 0% -
    and a "Motor over-current. HPP 0.0 A, RWP 24.7 A" from a bench hub with no CT
    breakout fitted and neither pump energised. Three separate defects.
    A STOPPED MOTOR CANNOT BE OVER-CURRENT
    GPIO 39 is a floating input-only pin. ct_read_deci_amps() already rejects one by
    testing the bias pedestal, which is a good check - but a floating pin WANDERS,
    and when it drifted through the 1250-2050 mV window the RMS of its own mains
    pickup came out as 24.7 A and held for the three cycles OC_CONFIRM asks for.
    The pedestal test stays. The gate that cannot be fooled is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
    [app_main.c, app_priv.h, app_sensors.c]
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2026-09-02 Relay test on /cal — momentary, because latching one could stop the plant
    Five buttons: the four hub float-emulation relays and the battery room fan. Each
    energises its relay for five seconds and the firmware releases it.
    NO LATCH AND NO OFF BUTTON, AND THAT IS THE SAFETY PROPERTY
    Every hub relay reads as a FAULT at the Aster when energised - tank full, raw
    water empty, dosing low, pressure trip (WIRING.md 7.2). De-energised means
    "plant permitted to run", which is exactly why a hub crash leaves the panel
    working on its own switches. A latching test control would hand somebody the
    ability to stop the plant by clicking a thing and walking away, and it would do
    it through the one interface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
    [app_main.c, app_priv.h, app_sensors.c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]
2026-09-02 Free heap in telemetry and on the dashboard header
    The overnight soak proved the hub survives eight hours. It could not have shown
    a slow leak, because nothing measured memory - and a leak announces itself by the
    hub restarting one night, which looks exactly like a brownout or a crash.
    Two figures, because they answer different questions:
    heap_free bounces with every HTTP response and MQTT publish. On its own it
    says almost nothing.
    heap_min the lowest EVER seen since boot. Only moves one way, so a leak
    shows there days before it shows anywhere else.
    Header carries the live figure, footer the low-water mark - next to Last reset
    and Bus errors, which is whe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
    [app_web.c, check_telemetry.py]
2026-09-02 Commissioning: LOG_SUMMARY_MS to 5000
    Three console lines every 5 s instead of 30, for the field visit. Raw
    millimetres continuously is how you tell a sensor looking at water from one
    looking at a wall, and a percentage cannot.
    Committed rather than left as a working-tree edit, which was my first instinct
    and was wrong. Uncommitted, the binary stamps itself 1dd9a07-DIRTY: you know the
    base commit but not the delta, so what is on the box cannot be reconstructed.
    That is tolerable on a bench and not on a plant, and it gives away the exact
    traceability the git-hash version scheme was adopted for.
    Restoring it is one revert of this commit and an OTA. The value carries its own
    warning at the de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
    [app_priv.h]
2026-09-02 A press must have a beginning: don't erase Wi-Fi on a released BOOT
    A reflashed hub came back advertising over BLE with its provisioning gone. Not
    the flash - the button.
    The flash sequence is hold BOOT, tap EN, release BOOT, and idf.py hard-resets the
    board over RTS when it finishes. The button task starts counting the moment it
    runs, so a hub that came back up with BOOT still down - somebody simply not
    having let go yet - counted to three and read the release as a deliberate Wi-Fi
    reset. On a bench that is a re-pair. On a roof it is a trip with a phone.
    The button is now armed only after it has been seen RELEASED at least once since
    boot. That is exactly the property wanted, stated direc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
    [app_main.c, app_priv.h]
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2026-09-04 RS485: say which node and which command, not just how many
    "rs485 err 300" reads as a degrading bus and sends you to the terminators.
    It took dividing by uptime by hand to see the rate was exactly +2 every
    20 s, which is POLL_CYCLE_MS * WQ_POLL_CYCLES - dead regular, and no cable
    fault is regular. The aggregate was pointing at one command on two nodes
    the whole time and had no way to say so.
    So count polls alongside failures, per node and per command. The ratio is
    the diagnosis: 148 failures means nothing, 148/148 is a command that has
    never once worked, 3/1480 is a healthy bus that drops the odd frame. Those
    want different responses and one number cannot tell them apart.
    Counted once per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
    [app_main.c, app_rs485.c, app_web.c]
2026-09-04 Hub PCB: KiCad project, CT front-end worked example, netlist checker
    PCB_HUB_MOTHERBOARD.md has been a complete net list with no board since
    2026-08-28. This starts the board, and starts it in the one way that keeps
    the spec authoritative: nothing is drawn that section 4 does not name, and
    a checker fails if that stops being true.
    hub.kicad_sch draws section 7, the CT front-end, as a worked example -
    bias divider, both 1k/100nF channels, both jacks. Verified two ways: ERC
    clean at 0 errors and 0 warnings, and the exported netlist diffed against
    section 7 by hand. BIAS carries R1.2, R2.1, C1.1, C2.1 and the RING of
    both jacks; GND has both sleeves. Symbol pin geometry was read out of the
    ins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
    [hub.kicad_sch]
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
